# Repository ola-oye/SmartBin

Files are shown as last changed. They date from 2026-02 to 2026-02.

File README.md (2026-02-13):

# SmartBin - Automated Organic Waste Processor 
## Overview

SmartBin is an automated system that converts organic waste into compost through a controlled drying and grinding process. The system features odor control using carbon filtration, automated waste level detection, and a custom-designed ESP32-based motherboard for complete process automation.

**Key Features:**
- Automated waste level monitoring using ultrasonic sensors
- Odor control system with carbon filter and exhaust fan
- Controlled drying via 50W heating element
- Automated grinding using 120W AC blender motor with PWM speed control
- Custom PCB design with high/low-voltage isolation
- FreeRTOS-based task management

---

## System Architecture

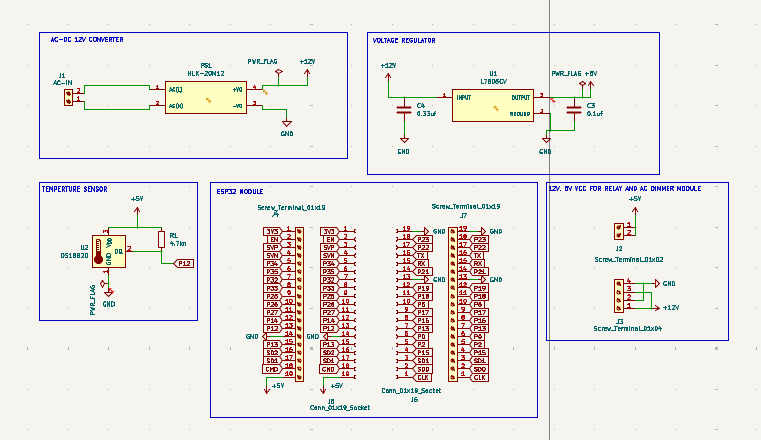
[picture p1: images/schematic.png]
System Block Diagram


*System Schematic*

### Process Flow:
1. **Waste Collection** → Ultrasonic sensor monitors fill level
2. **Odor Filtration** → Fan pulls air through carbon filter before exhaust
3. **Drying Stage** → Heating element activates at threshold level
4. **Grinding Stage** → AC motor pulverizes dried waste
5. **Storage** → Processed compost collected in separate compartment

---

## Hardware Design

### Custom Motherboard (KiCad)

PCB Front View
*Top layer of SmartBin control board*

PCB Back View
*Bottom layer showing power traces and isolation*

**Board Specifications:**
- **Controller:** ESP32-WROOM-32
- **Power Input:** 220V AC mains
- **AC Loads:** 120W blender motor, 50W heating element
- **DC Loads:** 5V fan, 3.3V control logic
- **Protection:** Fuse, optoisolators, flyback diodes
- **PCB Layers:** 2-layer, FR4
- **Dimensions:** [Add dimensions in mm]

### Key Components:

| Component | Purpose | Interface |
|---|---|---|
| ESP32 | Main controller | - |
| HC-SR04 | Waste level detection | GPIO |
| TRIAC + Optocoupler | AC motor speed control | PWM |
| Solid State Relay | Heating element control | GPIO |
| 12V/5V Regulators | DC power supply | - |
| Current Sensor | Motor load monitoring | ADC |

### Power Distribution:
```
220V AC ─┬─► AC Motor (via TRIAC dimmer)
         ├─► 50W Heater (via SSR)
         └─► AC-DC Converter ──► 12V ──► 5V ──► 3.3V ESP32
                                      ├─► Fan
                                      └─► Sensors
```
---

### Hardware Setup:

1. **Fabricate PCB:** Upload Gerber files to JLCPCB
2. **Solder Components:** Follow assembly drawing
3. **Connect Sensors:** Wire ultrasonic sensor to designated headers
4. **Power Connections:** 220V AC input via terminal block
5. **Motor Connection:** AC motor to TRIAC output
6. **Heater Connection:** Heating element to SSR output

## Testing & Validation

| Test | Method | Result |
|---|---|---|
| Motor speed control | Oscilloscope (PWM waveform) | ±5% accuracy |
| Temperature regulation | Thermocouple logging | ±2°C |
| Level detection | Manual measurement vs sensor | ±2mm |
| Power consumption | AC power meter | 125W max |
| Cycle time | Full dry → grind cycle | 45-60 min |

---

## Challenges & Solutions

| Challenge | Solution |
|---|---|
| AC motor EMI interfering with ESP32 | Added optoisolation, separate ground planes |
| Heating element overshoot | Implemented PID control instead of bang-bang |
| Moisture damage to electronics | Enclosed PCB in sealed compartment |
| Inrush current on motor start | Added soft-start PWM ramp |

---
## Future Improvements

- [ ] WiFi connectivity for remote monitoring
- [ ] Mobile app integration for status alerts
- [ ] Solar power compatibility
- [ ] Automatic compost quality sensing
- [ ] Multiple bin capacity expansion
- [ ] Machine learning for optimal cycle prediction

## Author

**Fatai Oyetunji**  
Computer Science, University of Lagos  
[GitHub](https://github.com/ola-oye) | [LinkedIn](https://linkedin.com/in/olasunkanmi)

---

## Acknowledgments

- University of Lagos Computer Science Department
- NitHub, University of Lagos
- Project supervisor and team members
- Open-source KiCad and ESP32 communities

---

**⭐ If you found this project useful, consider giving it a star!**

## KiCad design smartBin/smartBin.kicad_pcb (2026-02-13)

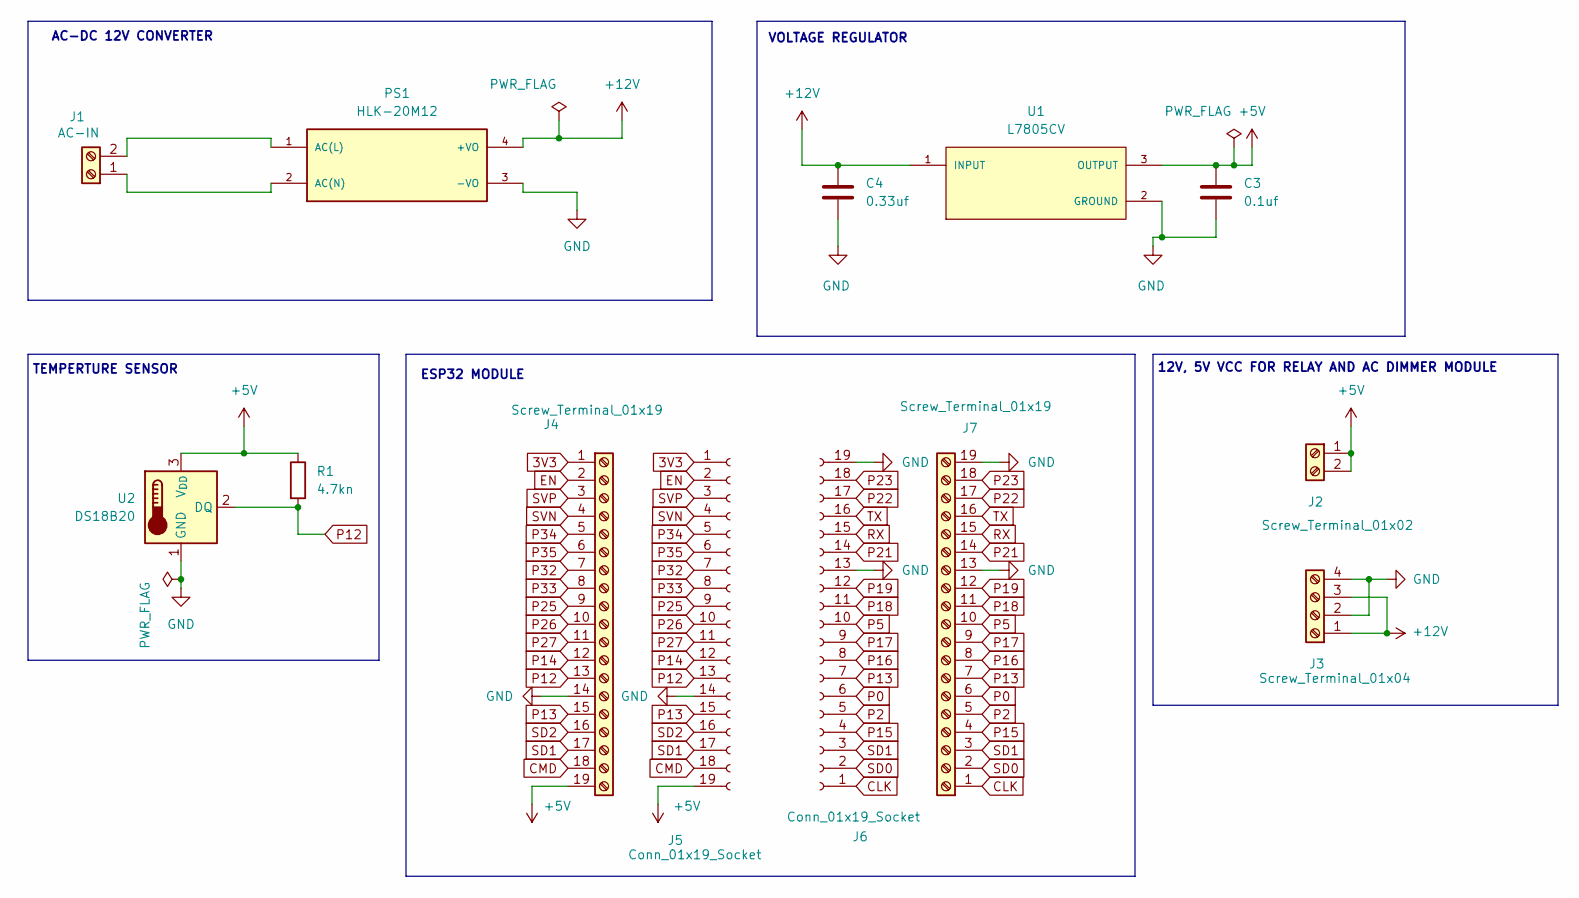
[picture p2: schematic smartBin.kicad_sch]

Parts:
C3: 0.1uf; C_0402_1005Metric_Pad0.74x0.62mm_HandSolder
C4: 0.33uf; C_0402_1005Metric_Pad0.74x0.62mm_HandSolder
J1: AC-IN; TerminalBlock_MaiXu_MX126-5.0-02P_1x02_P5.00mm
J2: Screw_Terminal_01x02; TerminalBlock_MaiXu_MX126-5.0-02P_1x02_P5.00mm
J3: Screw_Terminal_01x04; TerminalBlock_MaiXu_MX126-5.0-04P_1x04_P5.00mm
J4, J7: Screw_Terminal_01x19; TerminalBlock_MaiXu_MX126-5.0-19P_1x19_P5.00mm
J5, J6: Conn_01x19_Socket; PinSocket_1x19_P2.54mm_Vertical
PS1: HLK-20M12; CONV_HLK-20M12; PARTREV V1.3
R1: 4.7kn; R_0402_1005Metric_Pad0.72x0.64mm_HandSolder
U1: L7805CV; TO255P1040X460X1968-3; PARTREV 36
U2: DS18B20; TO-92_Inline

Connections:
3V3: J4.1, J5.1
+5V: C3.1, J2.1, J2.2, J4.19, J5.19, R1.1, U1.3 (OUTPUT), U2.3 (V_{DD})
+12V: C4.1, J3.1, J3.3, PS1.4 (+VO), U1.1 (INPUT)
CLK: J6.1, J7.1
CMD: J4.18, J5.18
EN: J4.2, J5.2
GND: C3.2, C4.2, J3.2, J3.4, J4.14, J5.14, J6.13, J6.19, J7.13, J7.19, PS1.3 (-VO), U1.2 (GROUND), U2.1 (GND)
unnamed: J1.1, PS1.2 (AC(N))
unnamed: J1.2, PS1.1 (AC(L))
P0: J6.6, J7.6
P2: J6.5, J7.5
P5: J6.10, J7.10
P12: J4.13, J5.13, R1.2, U2.2 (DQ)
P13: J4.15, J5.15, J6.7, J7.7
P14: J4.12, J5.12
P15: J6.4, J7.4
P16: J6.8, J7.8
P17: J6.9, J7.9
P18: J6.11, J7.11
P19: J6.12, J7.12
P21: J6.14, J7.14
P22: J6.17, J7.17
P23: J6.18, J7.18
P25: J4.9, J5.9
P26: J4.10, J5.10
P27: J4.11, J5.11
P32: J4.7, J5.7
P33: J4.8, J5.8
P34: J4.5, J5.5
P35: J4.6, J5.6
RX: J6.15, J7.15
SD0: J6.2, J7.2
SD1: J4.17, J5.17, J6.3, J7.3
SD2: J4.16, J5.16
SVN: J4.4, J5.4
SVP: J4.3, J5.3
TX: J6.16, J7.16

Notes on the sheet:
AC-DC 12V CONVERTER
12V, 5V VCC FOR RELAY AND AC DIMMER MODULE
ESP32 MODULE
TEMPERTURE SENSOR
VOLTAGE REGULATOR

Board: 2 copper layers, 13 parts (0 on the bottom side), 37 nets, no tracks yet.
